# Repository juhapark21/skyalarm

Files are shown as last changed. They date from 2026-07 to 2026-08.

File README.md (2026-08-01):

# Sky Alarm
The sky alarm from xkcd #2979! It tells you when cool space things are happening. 

skyalarm_cropped
Screenshot 2026-07-31 at 3 04 06 PM

## Why 
Sky Alarm
I also wanted this device. There are alert apps and telegram groups and RSS feeds out there, but I wanted something not tied to my phone or computer. I also thought it would be fun to make a large physical device in the style of the original comic. 

## Features 
- Siren turns on (sound and light) when a cool space thing is happening in your location 
- Only alerts for phenomena observable with the naked eye 
- Cool space things:
  - Lunar eclipses
  - Solar eclipses
  - Supermoons
  - ISS passes
- Configurable notification settings 

## Usage 
2. Strip a cable (USB-C to USB-C or USB-A to USB-C; if using the latter, strip the USB-C end).
3. Locate the power and ground cables.
4. Secure the power and ground cables to their corresponding screw terminals (labeled on the PCB).
5. Get two lengths of wire. Connect one end of each wire to the battery terminals of the siren. (You may need to disassemble or drill into the casing to access this)
6. Connect the remaining end of each wire to the siren screw terminals (labeled on the PCB).
7. Put in separate batteries for the siren. Make sure the switch is turned ON.
8. Plug in any USB-C to USB-C wall charger to the XIAO ESP32C3.
9. Plug in the external power cable. 

## Specifications 
- XIAO ESP32C3 microcontroller - edit firmware without any extra equipment
- MAX98357A - cheap and widely available amplifier 
- Any toy siren ~5V with an on-off switch and batteries should work
- 61.4 x 65.5 mm PCB - casing can be made smaller with different parts without adjusting the board
- Runs on any wall power supply 1A-3A (suggested) 
- bom can be found as bom.csv 

## Upcoming features 
- Weather checks - no alerts if overcast
- Description page for details about alerted event 
- Custom audio 
- Switching from API calls to local calculations for more predictable events 
- More cool space things!

## Images 
skyalarm_cropped

Screenshot 2026-07-31 at 3 04 06 PM

Screenshot 2026-07-31 at 2 35 29 PM

Screenshot 2026-07-31 at 2 35 40 PM

Screenshot 2026-07-31 at 2 35 59 PM

zine

## Credits 
Inspiration from [https://xkcd.com/2979/](https://xkcd.com/2979/) 

Font from [https://github.com/ipython/xkcd-font](https://github.com/ipython/xkcd-font) 

Screenshot 2026-07-31 at 7 51 07 PM

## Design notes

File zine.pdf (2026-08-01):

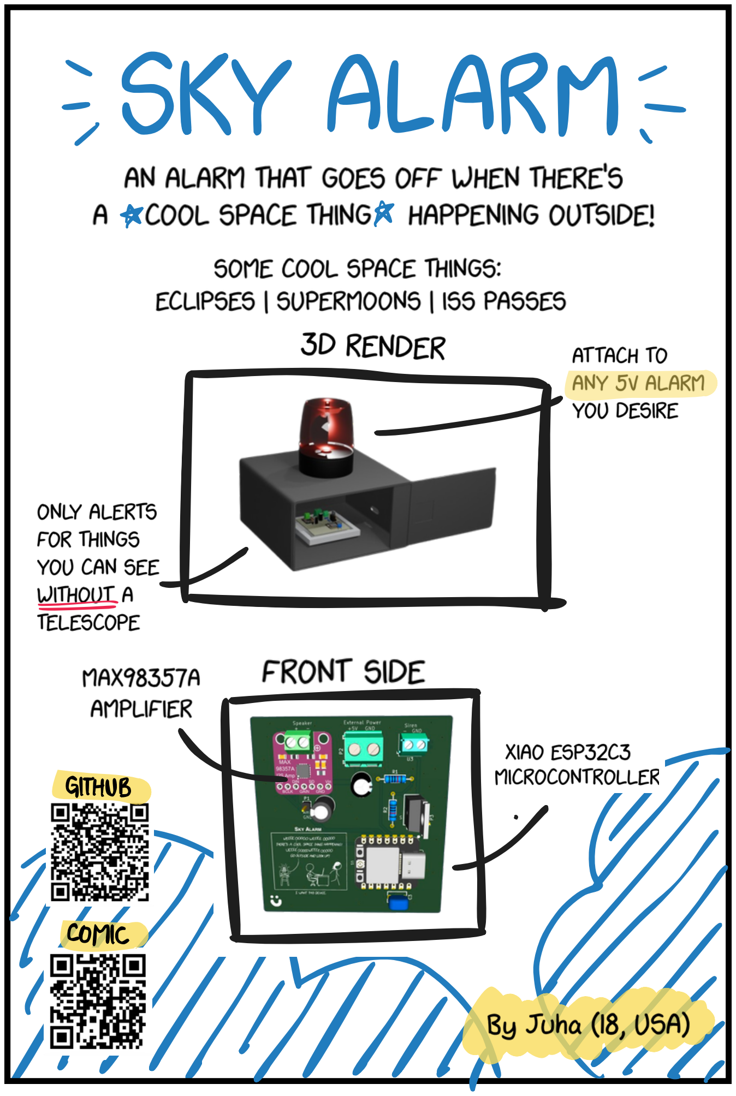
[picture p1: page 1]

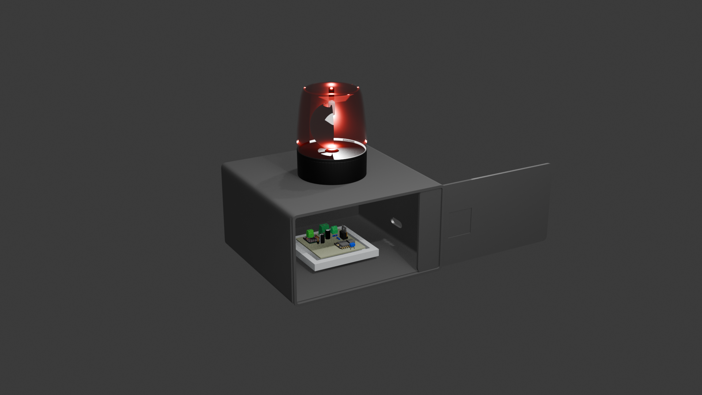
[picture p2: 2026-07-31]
3dmodels/render/SkyAlarm-render.png

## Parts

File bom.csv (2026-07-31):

Index | MPN | Manufacturer | Package | Description | RoHS | Quantity | MOQ | Multiple | Unit Price($) | Extended Price($) | Product Link
0 | CR2032-BS-6-1 | QIJEY | - | Battery Holder Coin CR2032 Cell SMD | yes | 5 | 5 | 5 | 0.1380 | 0.69 | https://www.lcsc.com/product-detail/C70377.html
1 | DOP150N03 | DOINGTER | TO-220 | N-Channel 30V 150A 109W Through Hole TO-220 | yes | 5 | 5 | 5 | 0.2231 | 1.12 | https://www.lcsc.com/product-detail/C42395896.html
2 | 28MM-4Ω3W-TFHM | XHXDZ | - | 5% 4Ω Electromagnetic 670Hz 99dB 3W Speakers RoHS | yes | 1 | 1 | 1 | 0.7732 | 0.77 | https://www.lcsc.com/product-detail/C50387214.html
3 | ERG25V220M6X11 | JIERR | Through Hole,D6.3xL11mm | 220uF 25V Aluminum Electrolytic Capacitors Through Hole,D6.3xL11mm 2000hrs@105℃ | yes | 10 | 10 | 10 | 0.0441 | 0.44 | https://www.lcsc.com/product-detail/C47344177.html
4 | KS107M025E07RR0VH2FP0 | Chengx | Through Hole,D6.3xL7mm | 100uF 25V Aluminum Electrolytic Capacitors Through Hole,D6.3xL7mm 1000hrs@105℃ | yes | 20 | 20 | 20 | 0.0242 | 0.48 | https://www.lcsc.com/product-detail/C44587.html
5 | KTD350B106K43A0T00 | NCC | Through Hole,P=5mm | 10uF ±10% 35V Through Hole,P=5mm Ceramic Capacitors RoHS | yes | 1 | 1 | 1 | 0.9782 | 0.98 | https://www.lcsc.com/product-detail/C32753248.html
6 | MF1/2WS-470Ω±1% T | CCO(Chian Chia Elec) | Through Hole,D2.3xL6.5mm | 470Ω 500mW 250V Metal Film Resistor ±100ppm/℃ ±1% Through Hole,D2.3xL6.5mm Through Hole Resistors RoHS | yes | 50 | 50 | 50 | 0.0107 | 0.54 | https://www.lcsc.com/product-detail/C129899.html
7 | MF1/4W-10KΩ±1% T | CCO(Chian Chia Elec) | Through Hole,D2.3xL6.5mm | 10kΩ 250mW 250V Metal Film Resistor ±100ppm/℃ ±1% Through Hole,D2.3xL6.5mm Through Hole Resistors RoHS | yes | 50 | 50 | 50 | 0.0113 | 0.57 | https://www.lcsc.com/product-detail/C119347.html
8 | 2.54-1*1P | BOOMELE(Boom Precision Elec) | Through Hole,P=2.54mm | Pin Header 1 Position Single Row Through Hole | yes | 50 | 50 | 50 | 0.0129 | 0.65 | https://www.lcsc.com/product-detail/C81276.html
9 | 1N5819 | ST | DO-41 | Diode 40V 1A Through Hole DO-41 | yes | 5 | 5 | 5 | 0.0956 | 0.48 | https://www.lcsc.com/product-detail/C110032.html
10 | WJ500V-5.08-2P | KANGNEX | Through Hole,P=5.08mm | 2 Position Wire to Board Terminal Block Through Hole 5.08mm | yes | 5 | 5 | 5 | 0.1244 | 0.62 | https://www.lcsc.com/product-detail/C8465.html
11 | DB301V-3.5-2P-GN-S | DORABO | Through Hole,P=3.5mm | 2 Position Wire to Board Terminal Block Through Hole 3.5mm | yes | 5 | 5 | 5 | 0.0874 | 0.44 | https://www.lcsc.com/product-detail/C695629.html
12 | 113991054 | Seeed Technology Co. Ltd | Through Hole | XIAO ESP32C3 - Cost Effective RISC-V MCU with Wi-Fi, BLE | yes | 1 | 1 | 1 | 4.99 | 4.99 | https://www.seeedstudio.com/Seeed-XIAO-ESP32C3-p-5431.html
13 | Y005 | YtotY | - | 3inch Rotating Red Flashing Beacon, 360 Degree Flashing Safety Warning Lights Emergency Light (red) | no | 1 | 1 | 1 | 9.99 | 9.99 | https://a.co/d/0jlY5ViY
14 | Mod-MAX98357-002 | GODIYMODULES | - | MAX98357 MAX98357A I2S 3W Class D Amplifier Breakout Interface I2S DAC Decoder | yes | 2 | 2 | 1 | 3.44 | 6.88 | https://a.co/d/01SNwV0x
Total price |  |  |  |  |  |  |  |  |  | 35.31

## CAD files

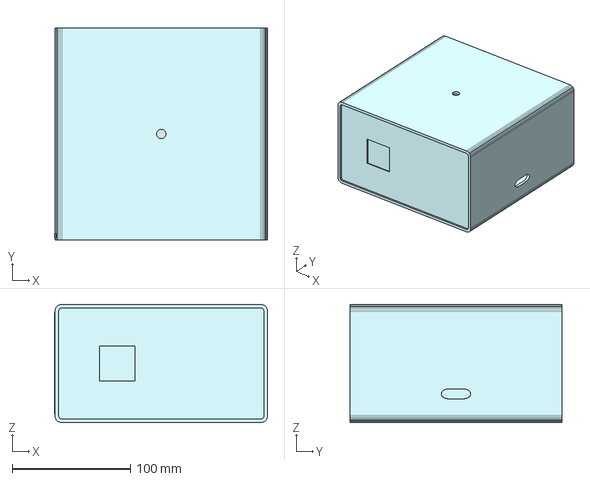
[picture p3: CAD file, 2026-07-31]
3dmodels/assembled/SkyAlarm-enclosureAssembled.step
180.5 x 180.0 x 100.0 mm

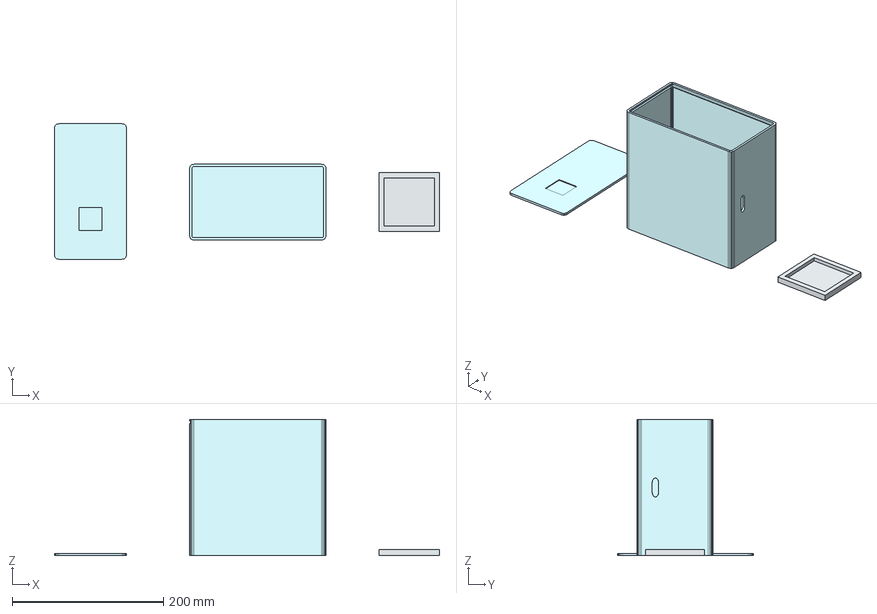
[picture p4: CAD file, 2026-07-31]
3dmodels/print/SkyAlarm-EnclosureDisassembled.step
508.5 x 179.0 x 180.0 mm

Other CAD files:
3dmodels/assembled/SkyAlarm-enclosureAssembled.f3d
3dmodels/print/SkyAlarm-EnclosureDisassembled.f3d

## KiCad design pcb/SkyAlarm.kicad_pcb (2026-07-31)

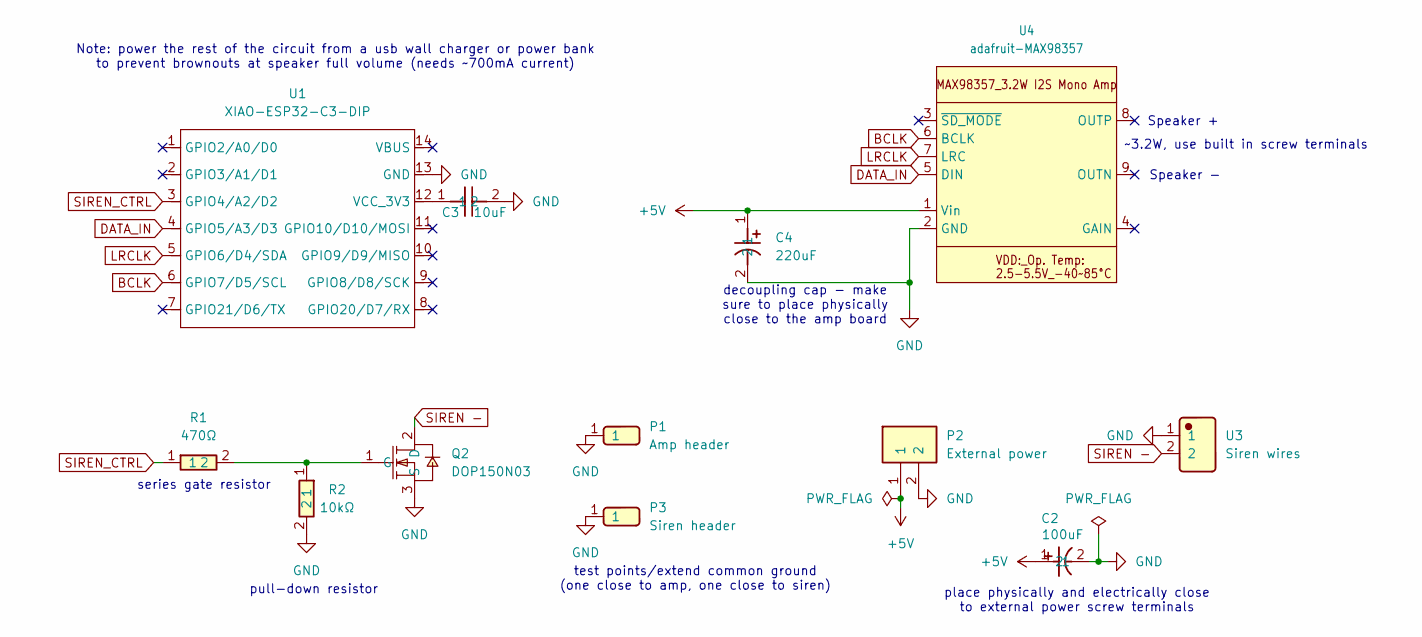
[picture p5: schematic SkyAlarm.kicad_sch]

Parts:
C2: 100uF; KS107M025E07RR0VH2FP0; Manufacturer Part KS107M025E07RR0VH2FP0; LCSC C44587
C3: 10uF; KTD350B106K43A0T00; Manufacturer Part KTD350B106K43A0T00; LCSC C32753248
C4: 220uF; ERG25V220M6X11; Manufacturer Part ERG25V220M6X11; LCSC C47344177
P1: Amp header; Header-Male-2_54_1x1; Manufacturer Part 2.54-1*1P针; LCSC C81276
P2: External power; WJ500V-5_08-2P-14-00A; Manufacturer Part WJ500V-5.08-2P; LCSC C8465
P3: Siren header; Header-Male-2_54_1x1; Manufacturer Part 2.54-1*1P针; LCSC C81276
Q2: DOP150N03; TO-220-3_L10.0-W4.5-P2.54-L-1; MPN DOP150N03; LCSC Part C42395896
R1: 470Ω; MF1_2WS-470_1_T52; Manufacturer Part MF1/2WS-470Ω±1% T; LCSC C129899
R2: 10kΩ; MF1_4W-10K_1_T52; Manufacturer Part MF1/4W-10KΩ±1% T; LCSC C119347
U1: XIAO-ESP32-C3-DIP; XIAO-ESP32C3-DIP
U3: Siren wires; DB301V-3_5-2P-GN; Manufacturer Part DB301V-3.5-2P-GN-S; LCSC C695629
U4: adafruit-MAX98357

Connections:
+5V: C2.1, C4.1, P2.1, U4.1 (Vin)
BCLK: U1.6 (GPIO7/D5/SCL), U4.6 (BCLK)
DATA_IN: U1.4 (GPIO5/A3/D3), U4.5 (DIN)
GND: C2.2, C3.2, C4.2, P1.1 (1_1), P2.2, P3.1 (1_1), Q2.3 (S), R2.2, U1.13 (GND), U3.1, U4.2 (GND)
LRCLK: U1.5 (GPIO6/D4/SDA), U4.7 (LRC)
unnamed: Q2.1 (G), R1.2, R2.1
unnamed: C3.1, U1.12 (VCC_3V3)
SIREN -: Q2.2 (D), U3.2
SIREN_CTRL: R1.1, U1.3 (GPIO4/A2/D2)

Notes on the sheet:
Note: power the rest of the circuit from a usb wall charger or power bank to prevent brownouts at speaker full volume (needs ~700mA current)
series gate resistor
pull-down resistor
~3.2W, use built in screw terminals
Speaker +
place physically and electrically close to external power screw terminals
decoupling cap - make sure to place physically close to the amp board
test points/extend common ground (one close to amp, one close to siren)
Speaker -

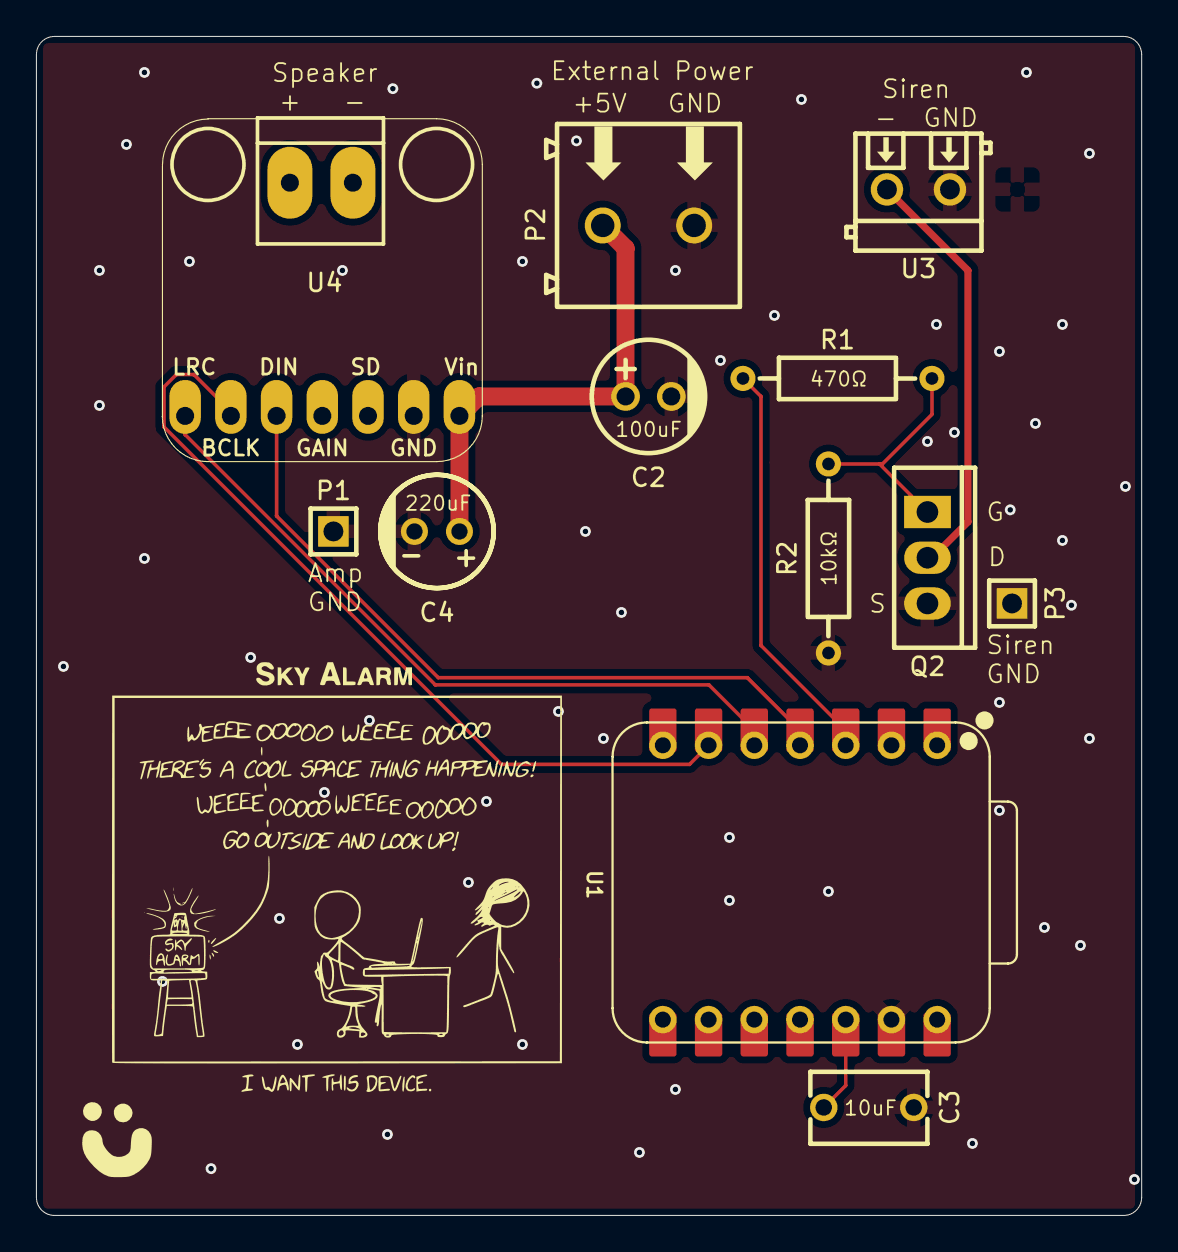
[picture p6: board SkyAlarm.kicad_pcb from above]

Board: 2 copper layers, 61.4 x 65.5 mm, 12 parts (0 on the bottom side), 9 nets.

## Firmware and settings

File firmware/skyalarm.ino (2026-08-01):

//https://randomnerdtutorials.com/esp32-date-time-ntp-client-server-arduino/ 
//https://github.com/espressif/arduino-esp32/blob/master/libraries/ESP32/examples/Time/SimpleTime/SimpleTime.ino 
//https://wiki.seeedstudio.com/XIAO_ESP32C3_WiFi_Usage/ 
//https://wiki.seeedstudio.com/XIAO_ESP32C3_Getting_Started/ 
//https://github.com/witnessmenow/arduino-sample-api-request/blob/master/ESP32/HTTP_GET_JSON/HTTP_GET_JSON.ino 
//https://github.com/pschatzmann/arduino-audio-tools/wiki/Working-with-PlatformIO

#include <Arduino.h>
#include <WiFi.h> 
#include <WiFiClientSecure.h>
#include <ArduinoJson.h>
#include <HTTPClient.h>
#include "time.h"
#include "esp_sntp.h"
#include "AudioTools.h"
#include "ESPUI.h"

const int led = D10; // indicator light (external) 
const int SIREN_CTRL = D2; 

// User specific info 
double lat = 37.4830; 
double lng = -122.2359; 

// Other configurable info 
bool notifsOn = true; 

// Notifications 
// Notifications begin 5 minutes before the event by default 
// (Also the grace period for sunrise/sunset checks) 
const int notifySecsBefore = 5 * 60; 
const int timeout = 60*1000; // time out after 1 min (not 1sec)
const long checkInterval = (15*60*1000); // check every 15 minutes 

// Element switches from 0 to 1 when notification is made for an event, and switches back to zero once the notification period for that event is over (or the event can no longer be found). 
// In this order: lunar-eclipse, solar-ecliipse, supermoon, ISS, TBD 
int eventsHappening[10] = {0, 0, 0, 0, 0, 0, 0, 0, 0, 0}; 


// Network 
const char* ssid = "Wokwi-GUEST";
const char* password = ""; 

// Only need HTTPS requests
WiFiClientSecure client; 

HTTPClient http;

// Time 
unsigned long previousMillis = 0; // last time of check 
bool firstTime = true; 

const char* ntpServer = "pool.ntp.org";
//const long gmtOffset_sec = 0; // match (close enough) with UTC 
//const int daylightOffset_sec = 3600;

// Audio 
AudioInfo info(44100, 2, 16);
SineWaveGenerator<int16_t> sineWave(32000);      // subclass of SoundGenerator with max amplitude of 32000
GeneratedSoundStream<int16_t> sound(sineWave);   // Stream generated from sine wave
I2SStream out; 
StreamCopy copier(out, sound);                   // copies sound into i2s

// UI 
uint16_t onOffSwitchID = 0; 

void setup() {
  Serial.begin(115200);
  delay(10); 

  // initialize digital pin led as an output
  pinMode(led, OUTPUT);

  // Connect to wifi  
  Serial.print("\n\nConnecting to wifi network");

  WiFi.begin(ssid, password); 
  while (WiFi.status() != WL_CONNECTED) {
    delay(500);
    Serial.print(".");
  }

  Serial.println("");
  Serial.println("WiFi connected");
  Serial.println("IP address: ");
  Serial.println(WiFi.localIP()); 

  // TODO: Actually verify later 
  client.setInsecure();

  // Set configured ntp servers and constant TimeZone/daylightOffset
  configTime(0, 0, ntpServer); // UTC?? pls 

  // Audio config 
  Serial.println("Starting I2S...");
  I2SConfig config = out.defaultConfig(TX_MODE); 
  config.pin_bck = 7; 
  config.pin_ws = 6; 
  config.pin_data = 5; 
  config.copyFrom(info);
  out.begin(config); 

  //ESPUI config 
  ESPUI.setVerbosity(Verbosity::Quiet); 
  onOffSwitchID = ESPUI.addControl(ControlType::Switcher, "Notifications", "1", ControlColor::Emerald, Control::noParent, &onOffCallback);
  ESPUI.begin("Sky Alarm Settings");

  printTime();
}

void loop() {
  // Every 15 minutes, trigger a check 
  unsigned long currentMillis = millis(); 

  if ((currentMillis - previousMillis >= checkInterval) || firstTime) {
    previousMillis = currentMillis; // update last time checked 

    //Serial.print("Free heap at start: ");
    //Serial.println(ESP.getFreeHeap());
    //Serial.println(ESP.getMaxAllocHeap());
    
    // The code below happens every 15 minutes 
    Serial.println("\nChecking for new phenomena...");

    // First of all, is it after sunset + before sunrise? 
    // Grace period = how much before the event notifications begin 
    
    //bool isNight = skyIsDark(notifySecsBefore);

    //Serial.print("The sky is dark: "); 
    //Serial.println(isNight);

    // If dark, check for lunar eclipses in the next 15 minutes 
    // https://opale.imcce.fr/api/v1/phenomena/eclipses/301/2026-08-27
    
    /*
    if (isNight == true) {
      lunarEclipse();
      superMoon(); 
    }
    
    solarEclipse(); 
    */

    ISS(); 

    firstTime = false; 
  }
  
  // Copy sound to out 
  copier.copy(); 
}

void lunarEclipse() {
  Serial.println("Checking for lunar eclipse...");

  // Get the date for the API call 
  char nowISO[25]; 
  nowTimeInUTCISO8601(nowISO, sizeof(nowISO)); 
  tm nowtm = tmFromISO8601(nowISO); 
  time_t nowEpoch = nowTimeInEpoch(); 

  char formattedDate[13]; 
  standardizedDateFromtm(nowtm, formattedDate, sizeof(formattedDate)); 
  String updatedURL = "https://opale.imcce.fr/api/v1/phenomena/eclipses/301/" + String(formattedDate);

  const char* forSureEclipseURL = "https://opale.imcce.fr/api/v1/phenomena/eclipses/301/2026-08-27"; 

  http.useHTTP10(true); 

  http.begin(client, updatedURL);
  int httpResponseCode = http.GET();
  
  if (httpResponseCode == HTTP_CODE_OK) {
    // Json parsing setup and filters 
    JsonDocument filter;

    JsonObject filter_response_lunareclipse_0 = filter["response"]["lunareclipse"].add<JsonObject>();

    JsonObject filter_response_lunareclipse_0_duration = filter_response_lunareclipse_0["duration"].to<JsonObject>();
    filter_response_lunareclipse_0_duration["partial"] = true;
    filter_response_lunareclipse_0_duration["total"] = true;

    JsonObject filter_response_lunareclipse_0_events = filter_response_lunareclipse_0["events"].to<JsonObject>();
    filter_response_lunareclipse_0_events["U1"]["date"] = true;
    // Don't need ending time of ecilpse rn 
    filter_response_lunareclipse_0_events["U4"]["date"] = false;
    filter_response_lunareclipse_0["type"] = true;

    JsonDocument doc;

    //Serial.print("Free heap before deserializeJson: ");
    //Serial.println(ESP.getFreeHeap());
    //Serial.println(ESP.getMaxAllocHeap());

    // Time out after 1min instead of 1sec 
    client.setTimeout(timeout); 
    DeserializationError error = deserializeJson(doc, http.getStream(), DeserializationOption::Filter(filter), DeserializationOption::NestingLimit(15));

    //Serial.print("Free heap after deserializeJson: ");
    //Serial.println(ESP.getFreeHeap());
    //Serial.println(ESP.getMaxAllocHeap());

    if (error) {
      Serial.print("deserializeJson() failed: ");
      Serial.println(error.c_str());
      return;
    }

    JsonObject response_lunareclipse_0 = doc["response"]["lunareclipse"][0];

    const char* response_lunareclipse_0_duration_partial = response_lunareclipse_0["duration"]["partial"];


    const char* eclipse_start_date_time = response_lunareclipse_0["events"]["U1"]["date"];

    /*
    char event_key[3]; 
    for (JsonPair response_lunareclipse_0_event : response_lunareclipse_0["events"].as<JsonObject>()) {
      const char* response_lunareclipse_0_event_key = response_lunareclipse_0_event.key().c_str(); // "U1", ...
      strncpy(event_key, response_lunareclipse_0_event_key, sizeof(response_lunareclipse_0_event_key - 1));
      event_key[sizeof(event_key) - 1] = '\0'; // null termination 
      const char* response_lunareclipse_0_event_value_date = response_lunareclipse_0_event.value()["date"];

    }
    */

    const char* response_lunareclipse_0_type = response_lunareclipse_0["type"]; // "PartialEclipse"

    if (response_lunareclipse_0.size() == 0) {
      Serial.println("No lunar eclipse today!");
      eventsHappening[0] = 0; 
    } else if (strcmp(response_lunareclipse_0_type, "PenumbralEclipse") == 0) {
      Serial.println("Just a penumbral eclipse today! It's not very visible with the naked eye."); 
      eventsHappening[0] = 0; 
    } else {
      // It's an eclipse! 
      Serial.print("There's a "); 
      Serial.print(response_lunareclipse_0_type);
      Serial.println(" today!"); 

      // Is it anywhere from -[notifySecsBefore]min to +halfway through the event? 
      time_t eclipse_start_epoch = epochFromISO8601(eclipse_start_date_time);
      int eclipse_partial_duration = secsFromDuration(response_lunareclipse_0_duration_partial);

      if (nowEpoch < eclipse_start_epoch) {
        // Eclipse hasn't started yet - only notify if [notifySecs] before 
        if ((eclipse_start_epoch - nowEpoch) <= notifySecsBefore) {
          if (eventsHappening[0] == 0) {
            // Notification for this event hasn't happened yet 
            notify(); 
            eventsHappening[0] = 1;          
          } 
        } else {
          // It's wayyy before the eclipse. Don't notify 
          eventsHappening[0] = 0; 
          Serial.println("...But not yet."); 
        }
      } else if ((nowEpoch >= eclipse_start_epoch) && (nowEpoch <= (eclipse_start_epoch + (eclipse_partial_duration / 2)))) {
        // Eclipse has started but it isn't halfway through yet 
        if (eventsHappening[0] == 0) {
          // Notification for this event hasn't happened yet 
          notify(); 
          eventsHappening[0] = 1; 
        }
      } else {
        // It's past the eclipse time. Don't notify 
        eventsHappening[0] = 0; 
        Serial.println("...But it's over or close to over.");
      }
    }

    
  } else {
    Serial.printf("HTTP Error code: %d\n", httpResponseCode); 
  }

  http.end();

}

void solarEclipse() {
  Serial.println("Checking for solar eclipse...");

  // Get the date for the API call 
  char nowISO[25]; 
  nowTimeInUTCISO8601(nowISO, sizeof(nowISO)); 
  tm nowtm = tmFromISO8601(nowISO); 
  time_t nowEpoch = nowTimeInEpoch(); 

  char formattedDate[13]; 
  standardizedDateFromtm(nowtm, formattedDate, sizeof(formattedDate)); 
  String updatedURL = "https://opale.imcce.fr/api/v1/phenomena/eclipses/10/" + String(formattedDate) + "?observer=" + String(lat) + "," + String(lng);

  const char* forSureEclipseURL = "https://opale.imcce.fr/api/v1/phenomena/eclipses/10/2029-01-14?observer=37.4830,-122.2359"; 

  http.useHTTP10(true); 

  http.begin(client, updatedURL);
  int httpResponseCode = http.GET();
  
  if (httpResponseCode == HTTP_CODE_OK) {
    // Json parsing setup and filters 
    // Stream& input;

    JsonDocument filter;

    JsonObject filter_response_data_0 = filter["response"]["data"].add<JsonObject>();

    JsonObject filter_response_data_0_duration = filter_response_data_0["duration"].to<JsonObject>();
    filter_response_data_0_duration["penumbral"] = true;
    filter_response_data_0_duration["umbral"] = true;

    JsonObject filter_response_data_0_events = filter_response_data_0["events"].to<JsonObject>();
    filter_response_data_0_events["P1"]["date"] = true;
    filter_response_data_0_events["P4"]["date"] = true;
    filter_response_data_0["type"] = true;

    JsonDocument doc;

    client.setTimeout(timeout); 
    DeserializationError error = deserializeJson(doc, client, DeserializationOption::Filter(filter));

    if (error) {
      Serial.print("deserializeJson() failed: ");
      Serial.println(error.c_str());
      return;
    }

    JsonObject response_data_0 = doc["response"]["data"][0];

    const char* response_data_0_duration_penumbral = response_data_0["duration"]["penumbral"];
    // response_data_0["duration"]["umbral"] is null

    for (JsonPair response_data_0_event : response_data_0["events"].as<JsonObject>()) {
      const char* response_data_0_event_key = response_data_0_event.key().c_str(); // "P1", "P4"

      const char* response_data_0_event_value_date = response_data_0_event.value()["date"];

    }

    const char* response_data_0_type = response_data_0["type"]; // "ObserverPartialEclipse"

    const char* eclipse_start_date_time = response_data_0["events"]["P1"]["date"];

    if (response_data_0.size() == 0 || response_data_0_duration_penumbral == nullptr) {
      Serial.println("No solar eclipse today!");
      eventsHappening[1] = 0; 
    } else {
      // It's an eclipse! 
      Serial.print("There's a "); 
      Serial.print(response_data_0_type);
      Serial.println(" today!"); 

      // Is it anywhere from -[notifySecsBefore]min to +halfway through the event? 
      time_t eclipse_start_epoch = epochFromISO8601(eclipse_start_date_time);
      int eclipse_partial_duration = secsFromDuration(response_data_0_duration_penumbral);

      if (nowEpoch < eclipse_start_epoch) {
        // Eclipse hasn't started yet - only notify if [notifySecs] before 
        if ((eclipse_start_epoch - nowEpoch) <= notifySecsBefore) {
          if (eventsHappening[1] == 0) {
            // Notification for this event hasn't happened yet 
            notify(); 
            eventsHappening[1] = 1;          
          } 
        } else {
          // It's wayyy before the eclipse. Don't notify 
          eventsHappening[1] = 0; 
          Serial.println("...But not yet."); 
        }
      } else if ((nowEpoch >= eclipse_start_epoch) && (nowEpoch <= (eclipse_start_epoch + (eclipse_partial_duration / 2)))) {
        // Eclipse has started but it isn't halfway through yet 
        if (eventsHappening[1] == 0) {
          // Notification for this event hasn't happened yet 
          notify(); 
          eventsHappening[1] = 1; 
        }
      } else {
        // It's past the eclipse time. Don't notify 
        eventsHappening[1] = 0; 
        Serial.println("...But it's over or close to over.");
      }
    }

    
  } else {
    Serial.printf("HTTP Error code: %d\n", httpResponseCode); 
  }

  http.end();

}

void superMoon() {

  Serial.println("Checking for supermoon...");

  // Get the date for the API call 
  char nowISO[25]; 
  nowTimeInUTCISO8601(nowISO, sizeof(nowISO)); 

  // nowISO contains seconds right now, get rid of last three characters 
  int len = strlen(nowISO); 
  nowISO[len - 3] = '\0'; 

  String updatedURL = "https://svs.gsfc.nasa.gov/api/dialamoon/" + String(nowISO);

  const char* forSureEclipseURL = "https://svs.gsfc.nasa.gov/api/dialamoon/2026-11-24T14:54"; 

  http.useHTTP10(true); 

  http.begin(client, updatedURL);
  int httpResponseCode = http.GET();
  
  if (httpResponseCode == HTTP_CODE_OK) {
    // Json parsing setup and filters 
    // Stream& input;

    JsonDocument filter;
    filter["phase"] = true;
    filter["obscuration"] = true;
    filter["distance"] = true;

    JsonDocument doc;

    client.setTimeout(timeout); 
    DeserializationError error = deserializeJson(doc, client, DeserializationOption::Filter(filter));

    if (error) {
      Serial.print("deserializeJson() failed: ");
      Serial.println(error.c_str());
      return;
    }

    float phase = doc["phase"]; // 99.81
    int obscuration = doc["obscuration"]; // 0
    long distance = doc["distance"]; // 360850

    if ((phase >= 99.8f) && (distance <= 367520)) {
      // It's a supermoon! 
      Serial.println("There's a supermoon right now!"); 
      // Since this is a phase of the moon and not an isolated event, not notifying x seconds before. 
      // If anything. 99.8% illumination _is_ the notification before the actual full moon (which is usually a higher illumination %)
      if (eventsHappening[2] == 0) {
        // Hasn't been notified for yet 
        notify(); 
        eventsHappening[2] = 1; 
      } else {
        // Notification for this ongoing event has already happened once 
      }
    } else {
      // No supermoon today 
      Serial.println("No supermoon right now!");
      eventsHappening[2] = 0; 
    }
    
  } else {
    Serial.printf("HTTP Error code: %d\n", httpResponseCode); 
  }

  http.end();
}

void ISS() {
  Serial.println("Checking for ISS passes...");
  String updatedURL = "https://iss-api.polluxlabs.io/iss-pass?lat=" + String(lat) + "&lon=" + String(lng) + "&visible_only=true"; 

  // This may change in the future because this is not time-specific
  const char* forSureURL = "https://iss-api.polluxlabs.io/iss-pass?lat=52.52&lon=13.40"; 

  http.begin(client, updatedURL);
  int code = http.GET();

  if (code == 200) {
    JsonDocument doc;
    deserializeJson(doc, http.getStream());
    const char* riseTime = doc["passes"][0]["rise"]["time"];
    const char* culminationTime = doc["passes"][0]["culmination"]["time"];
    const char* compassDirection = doc["passes"][0]["rise"]["compass"]; 
    const char* riseAzimuth = doc["passes"][0]["rise"]["azimuth_deg"];
    // Max elevation in degrees 
    int elevation  = doc["passes"][0]["culmination"]["elevation_deg"];

    JsonObject passes_0 = doc["passes"][0];

    if (passes_0.size() == 0) {
      // No visible passes 
      Serial.println("No visible passes!"); 
      eventsHappening[3] = 0; 
    } else {
      // Visible passes exist - but is it happening soon/now? 
      Serial.println("There's a visible pass!");
      // Check upcoming one (passes[0]) 
      char nowISO[25]; 
      nowTimeInUTCISO8601(nowISO, sizeof(nowISO)); 
      time_t nowEpoch = nowTimeInEpoch(); 
      time_t passEpoch = epochFromISO8601(riseTime); 
      time_t culminationEpoch = epochFromISO8601(culminationTime);

      if (nowEpoch < passEpoch) {
        // Pass hasn't happened yet - less than 15+ mins before it happens? 
        int threshold; 

        if (notifySecsBefore >= 15) {
          // Use the user defined setting, it's fine 
          threshold = notifySecsBefore; 
        } else {
          // The user defined notif setting is too short to reliably alert for the ISS - make it 15mins
          threshold = (15*60); 
        }

        if ((passEpoch - nowEpoch) <= threshold) {
          // It is happening soon! Notify 
          if (eventsHappening[3] == 0) {
            notify(); 
            eventsHappening[3] = 1; 
          }
        } else {
          // It is too early to notify 
          Serial.println("...But not yet."); 
          eventsHappening[3] = 0; 
        }
      } else {
        // Pass is happening or has already happened 
        // Only notify if it is at culmination time or before 
        if (nowEpoch <= culminationEpoch)  {
          // It's started but still early enough to issue a notif 
          if (eventsHappening[3] == 0) {
            notify(); 
            eventsHappening[3] = 1; 
          } 
        } else {
          // It's too late to notify :( 
          Serial.println("...But it's already happened."); 
          eventsHappening[3] = 0; 
        }
      }

    }

  } else {
    Serial.printf("HTTP error: %d\n", code);
  }
  http.end();
}

JsonDocument jsonFromRequest(const char* urlBase, const char* everythingElse) {

  // Use the ArduinoJson Assistant to calculate this:
  // StaticJsonDocument<192> doc;
  // DynamicJsonDocument is deprecated 
  JsonDocument doc; //For ESP32/ESP8266 you'll mainly use dynamic.

  // Opening connection to server (Use 80 as port if HTTP)
  if (!client.connect(urlBase, 443))
  {
    Serial.println(F("Connection failed"));
    return doc;
  }

  // give the esp a breather
  yield();

  // Send HTTP request
  client.print(F("GET "));
  // This is the second half of a request (everything that comes after the base URL)
  client.print(everythingElse); // %2C == ,
  client.println(F(" HTTP/1.1"));

  //Headers
  client.print(F("Host: "));
  client.println(urlBase);

  client.println(F("Cache-Control: no-cache"));

  if (client.println() == 0)
  {
    Serial.println(F("Failed to send request"));
    return doc;
  }
  //delay(100);
  // Check HTTP status
  char status[32] = {0};
  client.readBytesUntil('\r', status, sizeof(status));
  if (strcmp(status, "HTTP/1.1 200 OK") != 0)
  {
    Serial.print(F("Unexpected response: "));
    Serial.println(status);
    return doc;
  }

  // Skip HTTP headers
  char endOfHeaders[] = "\r\n\r\n";
  if (!client.find(endOfHeaders))
  {
    Serial.println(F("Invalid response"));
    return doc;
  }

  // This is probably not needed for most, but I had issues
  // with the Tindie api where sometimes there were random
  // characters coming back before the body of the response.
  // This will cause no harm to leave it in
  // peek() will look at the character, but not take it off the queue
  while (client.available() && client.peek() != '{')
  {
    char c = 0;
    client.readBytes(&c, 1);
    yield();
    //Serial.print(c);
    //Serial.println("BAD");
  }

  //  // While the client is still availble read each
  //  // byte and print to the serial monitor
  //  while (client.available()) {
  //    char c = 0;
  //    client.readBytes(&c, 1);
  //    Serial.print(c);
  //  }

  
  DeserializationError error = deserializeJson(doc, client);

  // if (!error)

  return doc; 

}

void notify() {
  if (notifsOn) {
    // Placeholder for when testing without actual hardware 
    digitalWrite(led, HIGH);   // turn the LED on 
    Serial.println("WEE OOO WEE OOO"); 
    Serial.println("A SPACE THING IS HAPPENING");
    delay(10000);               // wait for 10 seconds
    digitalWrite(led, LOW);    // turn the LED off
    delay(10);
  }
}

void siren() {
  digitalWrite(SIREN_CTRL, HIGH);
  sineWave.begin(info, N_B4);  
  delay(10000); 
  digitalWrite(SIREN_CTRL, LOW); 
  sineWave.end(); 
}

#pragma region Various time formatting functions 
void nowTimeInUTCISO8601(char* result, size_t resultSize) {
  struct tm timeinfo; 
  if(!getLocalTime(&timeinfo)){
    Serial.println("Failed to obtain time :(");
    result[0] = '\0'; // result will be empty?? Hopefully?? When unable to obtain time 
    return; 
  }

  strftime(result, resultSize, "%Y-%m-%dT%H:%M:%S", &timeinfo);
  
  //Serial.println(&timeinfo, "%Y-%m-%dT%H:%M:%S");
  // Day of week/month/day of month/year/hour(24hr)/hour(12hr)/minute/second 
  //Serial.println(&timeinfo, "%A, %B %d %Y %H:%M:%S");
}

void localTimeToUTCISO8601(char* result, size_t resultSize) {
  int tzHour = 0, tzMin = 0; 
  char sign = '+';

}
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
